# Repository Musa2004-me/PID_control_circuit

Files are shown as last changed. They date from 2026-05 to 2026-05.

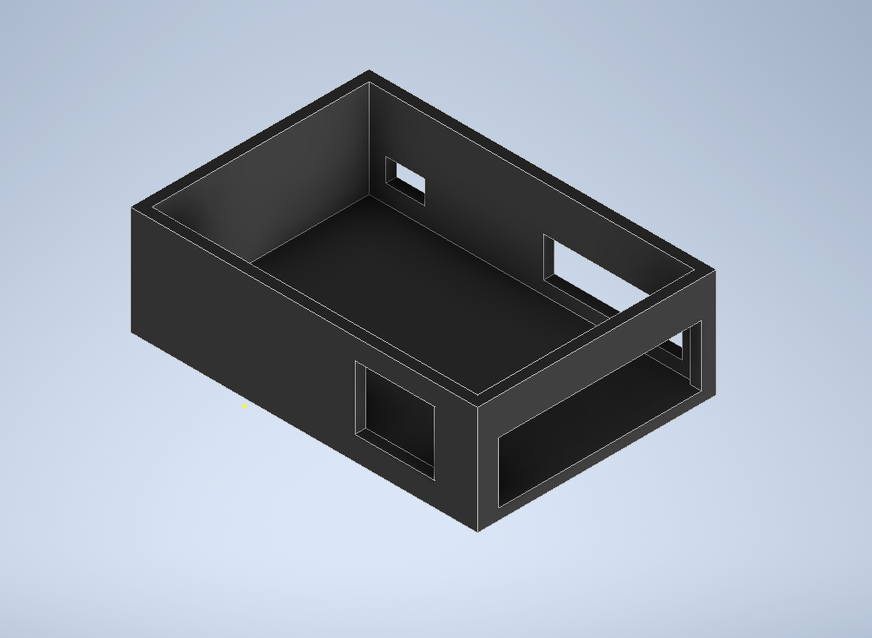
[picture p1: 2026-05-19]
ENCLOSURE.png

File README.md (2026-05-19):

# Analog PID Control Circuit

**Electronics for Instrumentation — MCT232s | Ain Shams University**
Team 27 — Musa Gamal, Fares Mohamed, Youssef Kamel

---

## What is this project?

This project is a fully analog PID controller built using op-amps. It controls the position angle of a DC motor by continuously comparing the desired setpoint (set by a potentiometer) against the actual motor position (read by an encoder), and adjusting the motor drive signal to minimize the error.

The analog circuit is connected to an Arduino UNO which interfaces with MATLAB Simulink for real-time monitoring and a DAC (MCP4725) to close the feedback loop.

---

## How it works

A potentiometer sets the desired angle as a voltage. A subtractor op-amp computes the error between the setpoint and the feedback. That error is then processed by three parallel op-amp stages — Proportional, Integral, and Derivative — whose outputs are summed and sent to the motor driver.

Each of the three gains (Kp, Ki, Kd) is adjustable in real time using potentiometers on the PCB.

---

## The Circuit

The full circuit was designed and simulated in Proteus. It includes input buffering, two low-pass filters to remove noise, a subtractor, the PID block, an adder, and output scaling amplifiers to match the Arduino's 5V ADC range.

---

## PID Gains

| Term | Gain Range | Components |
|---|---|---|
| Proportional (Kp) | 0 → 100 | 100kΩ pot, 1kΩ resistor |
| Integral (Ki) | 55 → 666 | 50kΩ pot, 5kΩ resistor, 0.3µF cap |
| Derivative (Kd) | 0 → 88 | 200kΩ pot, 440µF cap |

---

## Simulation Results

The full closed-loop system was simulated in Simulink with the motor modeled as:

$$G(s) = \frac{1}{s^2 + 10s + 20}$$

With a step input the system settles in around 4 seconds with no overshoot.

Setting the setpoint to 2.51V in the hardware-in-the-loop test, the output tracked it closely at ~2.5V.

---

## PCB

The board was designed using the LM348N quad op-amp IC to keep it as compact as possible. The three potentiometers for Kp, Ki, Kd are accessible on the top of the board.

---

## Tools

- **Proteus** — circuit simulation
- **MATLAB Simulink** — system simulation and hardware-in-the-loop testing
- **Arduino UNO** — analog interface
- **MCP4725** — DAC for feedback signal
- **LM348N / µA741** — op-amps

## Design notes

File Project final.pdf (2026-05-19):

AIN SHAMS UNIVERSITY-FACULTY OF ENGINEERING

## [MCT232s]

Electronics for Instrumentation

PID control circuit

## Project report

## Team 27

Name | ID | Section (MCT)
Musa Gamal El-Shenawy | 2100614 | 1
Fares Mohamed Mostafa | 2100409 | 1
Youssef Kamel Ahmed | 2101081 | 1

Table of Contents

### Introduction:

A PID controller, which stands for Proportional-Integral-Derivative controller, is a widely used tool in industrial control systems for regulating various physical quantities like temperature, flow, pressure, and speed. It utilizes a feedback loop to continuously monitor and adjust a process variable to match a desired setpoint.

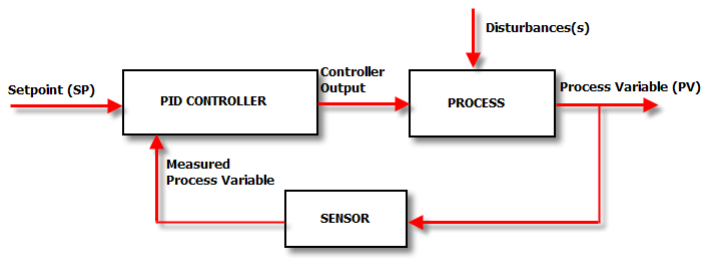
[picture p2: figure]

Operation principle:
1. Measures the Error: The PID controller constantly watches the difference between the setpoint (SP) and the actual measured value of the output (PV), calculating the error.
2. Threefold Response: The controller then calculates a response based on three terms:
- Proportional (P) Term: This term reacts to the current magnitude of the error. A larger error results in a larger response from the controller.

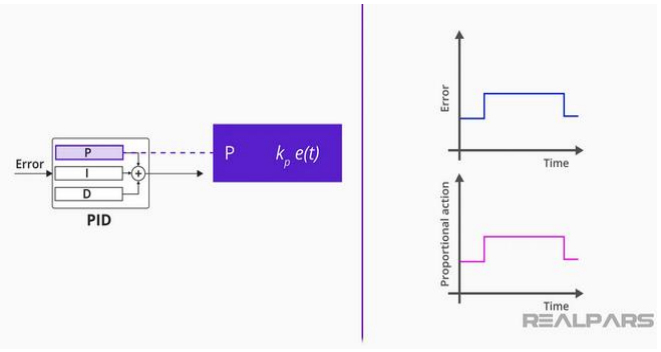
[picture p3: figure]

- Integral (I) Term: This term addresses long-term errors by accumulating the error over time. It helps eliminate any steady-state error, where the process variable remains slightly off the setpoint.
- Derivative (D) Term: This term anticipates future errors based on the rate of change of the error signal. It helps the controller react quickly to changes and reduces overshoot, where the process variable briefly goes beyond the desired setpoint.

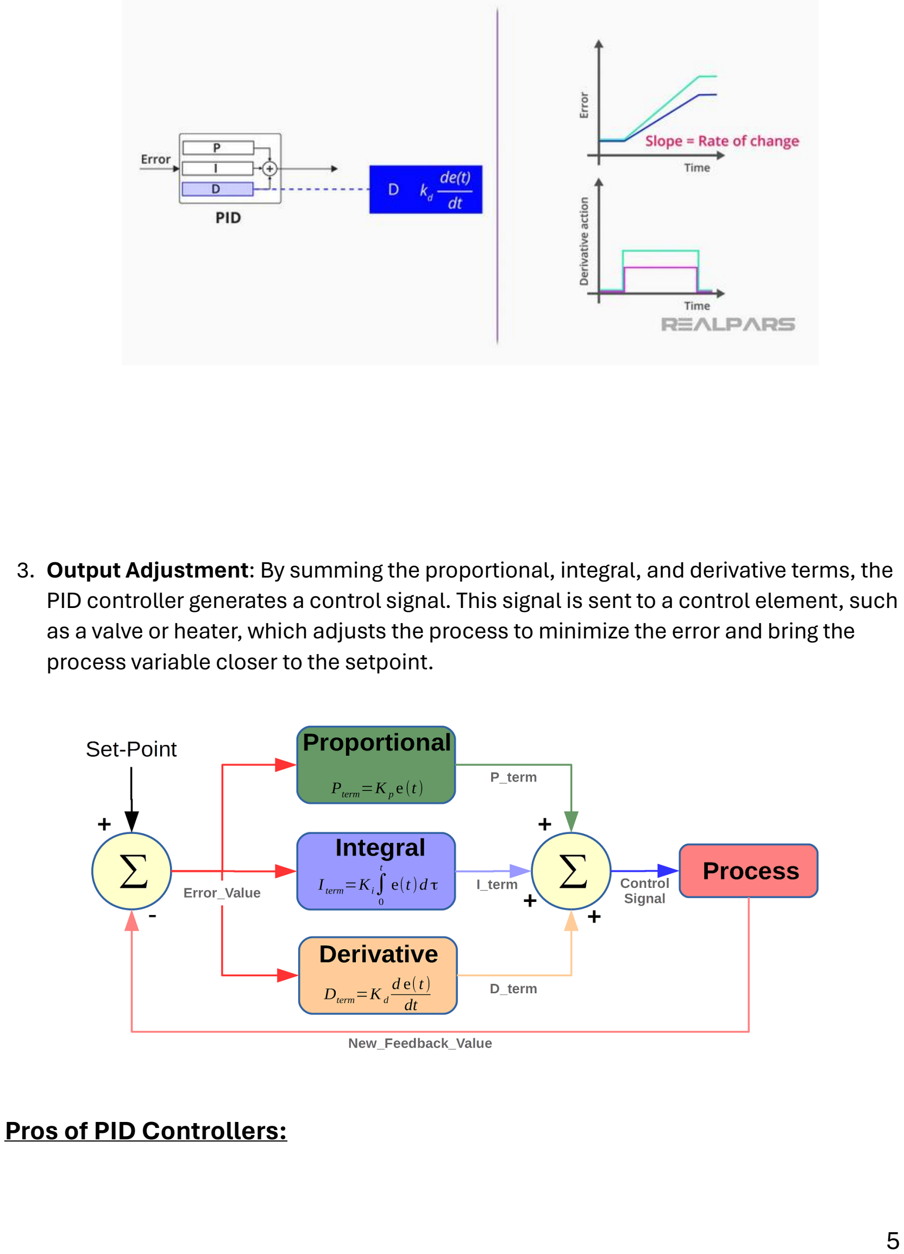
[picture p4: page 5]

3. Output Adjustment: By summing the proportional, integral, and derivative terms, the PID controller generates a control signal. This signal is sent to a control element, such as a valve or heater, which adjusts the process to minimize the error and bring the process variable closer to the setpoint.

Pros of PID Controllers:

Versatility: They can be applied to a vast range of processes thanks to their adjustable parameters. They can handle variables like temperature, pressure, flow, and speed across various industries.
Effectiveness: The combination of proportional, integral, and derivative actions in a PID controller allows for precise and stable control. The proportional term reacts immediately to errors, the integral term eliminates long-term drifts, and the derivative term anticipates future changes to prevent overshoot.
Simplicity: The core concept behind PID control is relatively easy to understand. While tuning the specific parameters (P, I, D) requires some know-how, the basic principles are accessible.
Cost-effective: PID controllers can be implemented using various technologies, from analog circuits to digital microprocessors. This makes them adaptable and affordable for a wide range of applications.

Cons of PID Controllers:

Tuning Time: While the concept is simple, achieving optimal performance from a PID controller requires careful tuning of the proportional, integral, and derivative gains. This tuning process can be time-consuming, especially for complex systems.
Limitations with Non-Linear Systems: PID controllers work best with linear systems where the output has a proportional relationship to the input. In highly non-linear systems, achieving optimal control with a PID controller can be challenging.
Not Ideal for Processes with Large Time Delays: If there's a significant delay between the control action and the observed effect in the process, a PID controller might struggle to maintain stability.

### Project objective:

The project objective is to design a PID circuit using op amps to control a motor position-angle when an input set-point is used with minimal error and fastest speed possible.

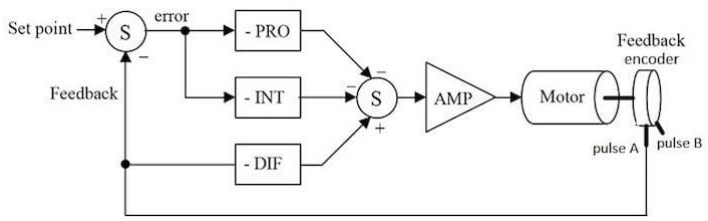
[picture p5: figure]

Desired response:
1. Risetime: the time the response rise to the set point.
2. Overshoot: is the amount the value rise above the set point

3. Settling time: the time the response settles to steady state.
4. steady-state error: the value that the response stays on away from the setpoint. -And they all should be minimised

These parameters can be controlled using the value of Kp,Ki,Kd

## Circuit:

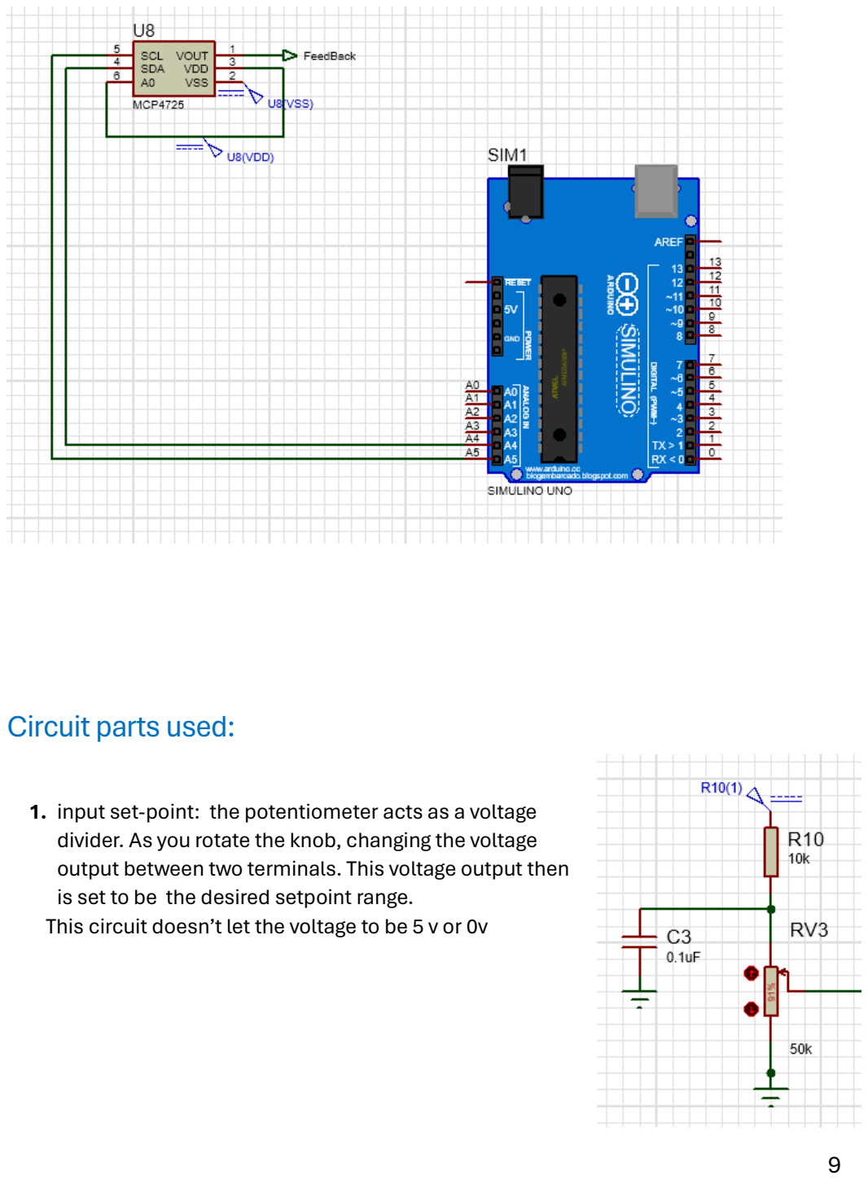
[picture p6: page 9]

### Circuit parts used:

### 1. input set-point: the potentiometer acts as a voltage

divider. As you rotate the knob, changing the voltage output between two terminals. This voltage output then is set to be the desired setpoint range.
This circuit doesn’t let the voltage to be 5 v or 0v

### 2. buffer: A buffer is used to isolate the load from the

source.

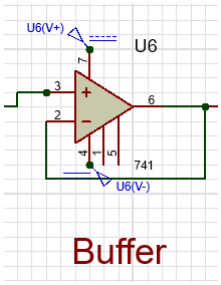
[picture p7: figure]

3. inverting amplifier: it is used to make the the signal positive with unity gain.

### 4. low-pass filter: a filter is added before the circuit

to remove any high frequency noise from the system.
And to rise the voltage smoothly .

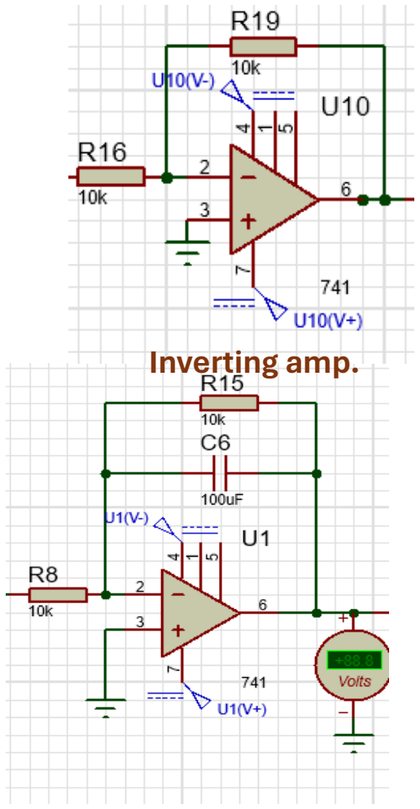
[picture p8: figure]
Inverting amp.

feedback

### 5. Subtractor: The subtractor is used as a

comparator it compares the feedback with the input signal and check if there is an error.

### 6. Low-pass filter:

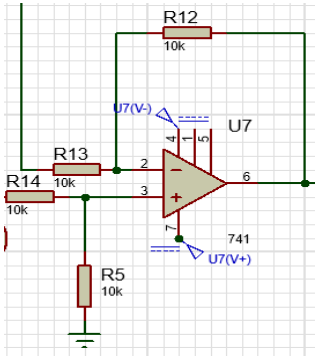
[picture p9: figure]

a filter is added before the circuit to remove any high frequency noise from the system.

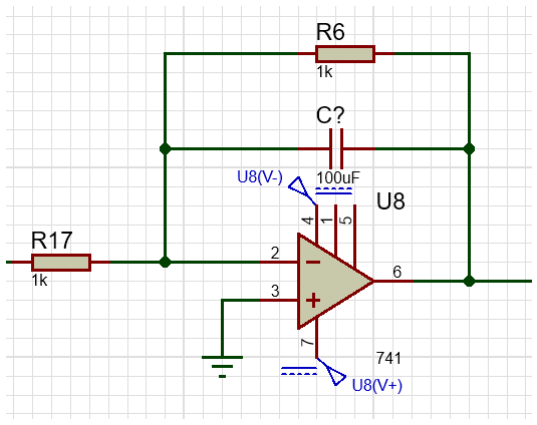
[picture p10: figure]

### 7. Proportional amplifier: An inverting amplifier configuration can be used to directly

scale the error signal (difference between setpoint and process variable).

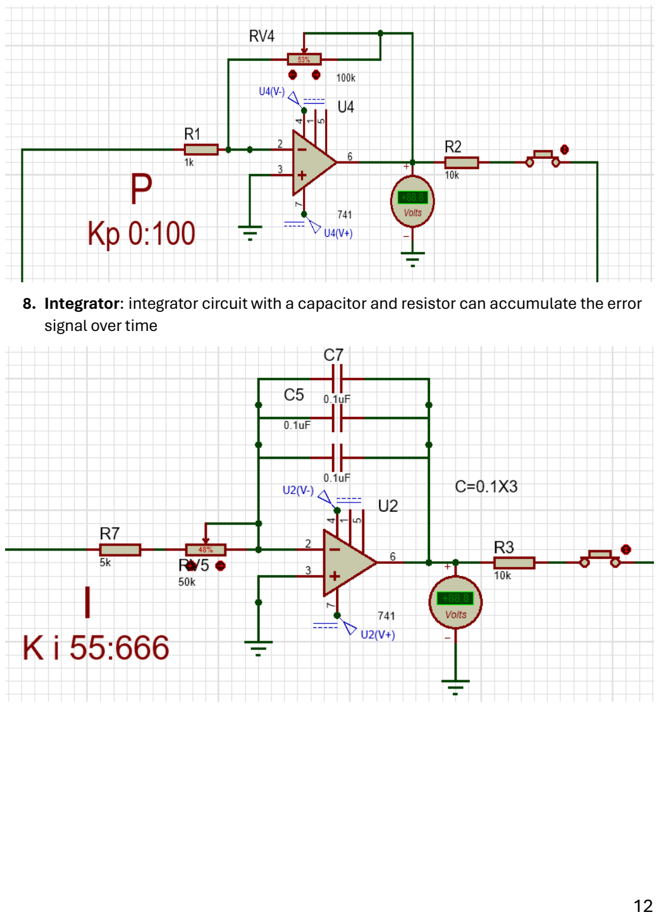
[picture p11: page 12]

### 8. Integrator: integrator circuit with a capacitor and resistor can accumulate the error

signal over time

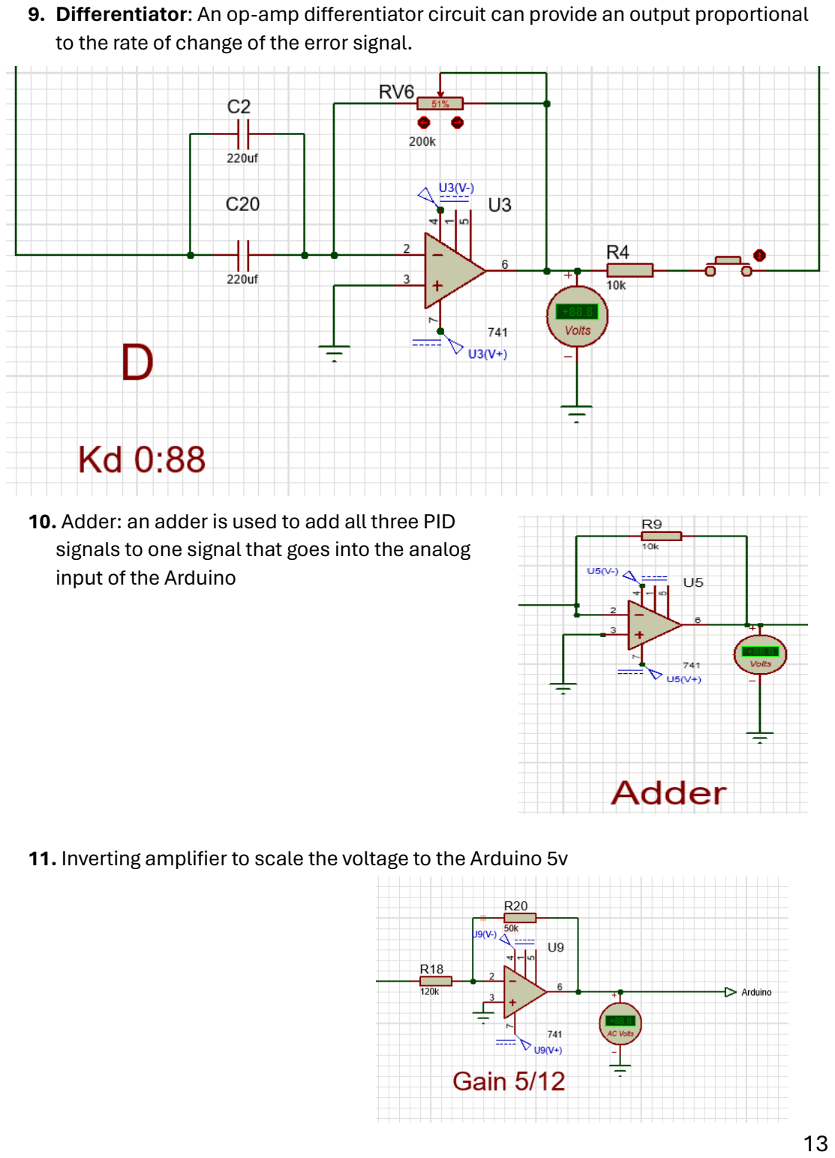
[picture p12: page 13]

### 9. Differentiator: An op-amp differentiator circuit can provide an output proportional

to the rate of change of the error signal.

### 10. Adder: an adder is used to add all three PID

signals to one signal that goes into the analog input of the Arduino

### 11. Inverting amplifier to scale the voltage to the Arduino 5v

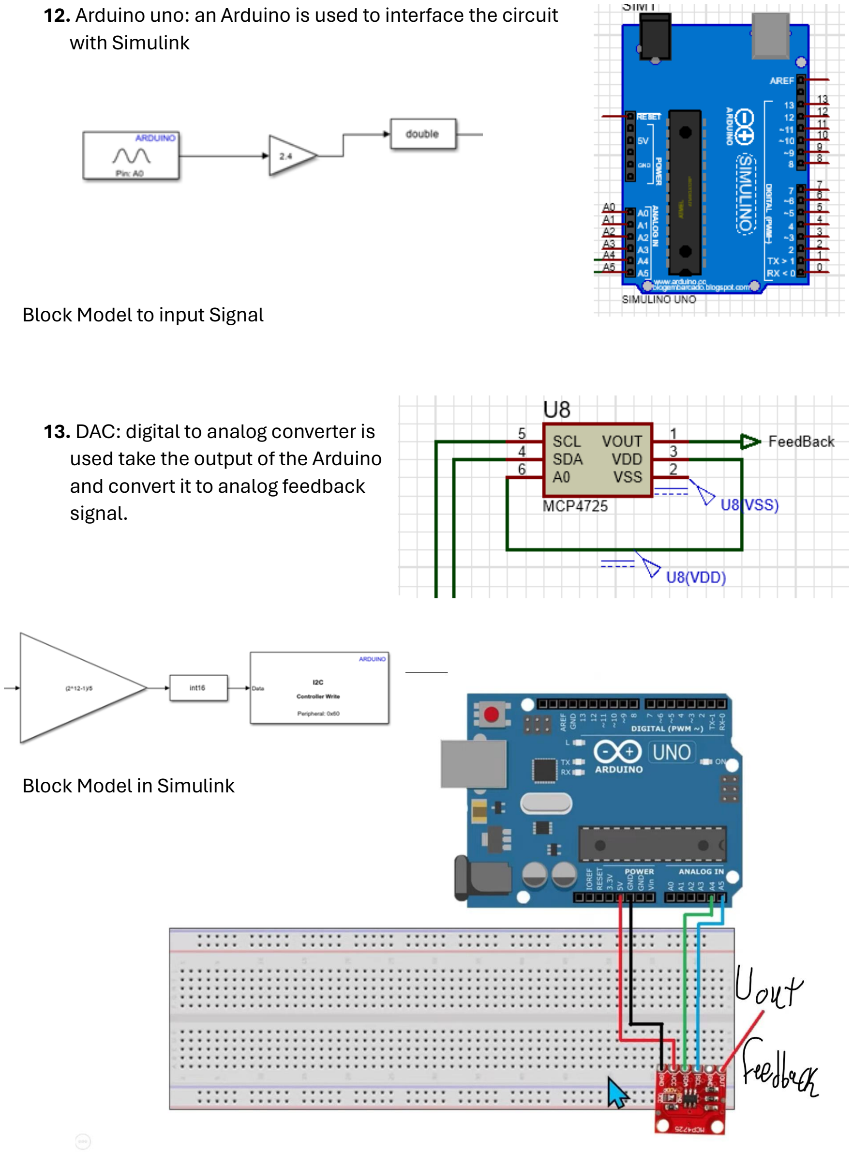
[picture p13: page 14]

### 12. Arduino uno: an Arduino is used to interface the circuit

with Simulink

Block Model to input Signal

### 13. DAC: digital to analog converter is

used take the output of the Arduino and convert it to analog feedback signal.

Block Model in Simulink

### Calculations:

1)Set Point <5v
From this ratio I can reach 0.84v and less V(max)=5x

50
60

=4.167v
V(min)=0v

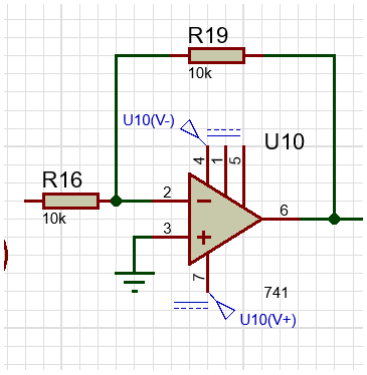
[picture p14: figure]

2)inverting Amp with Gain=-1Vset Av=-1

### 3) buffer

V1=V2
A(v)=1

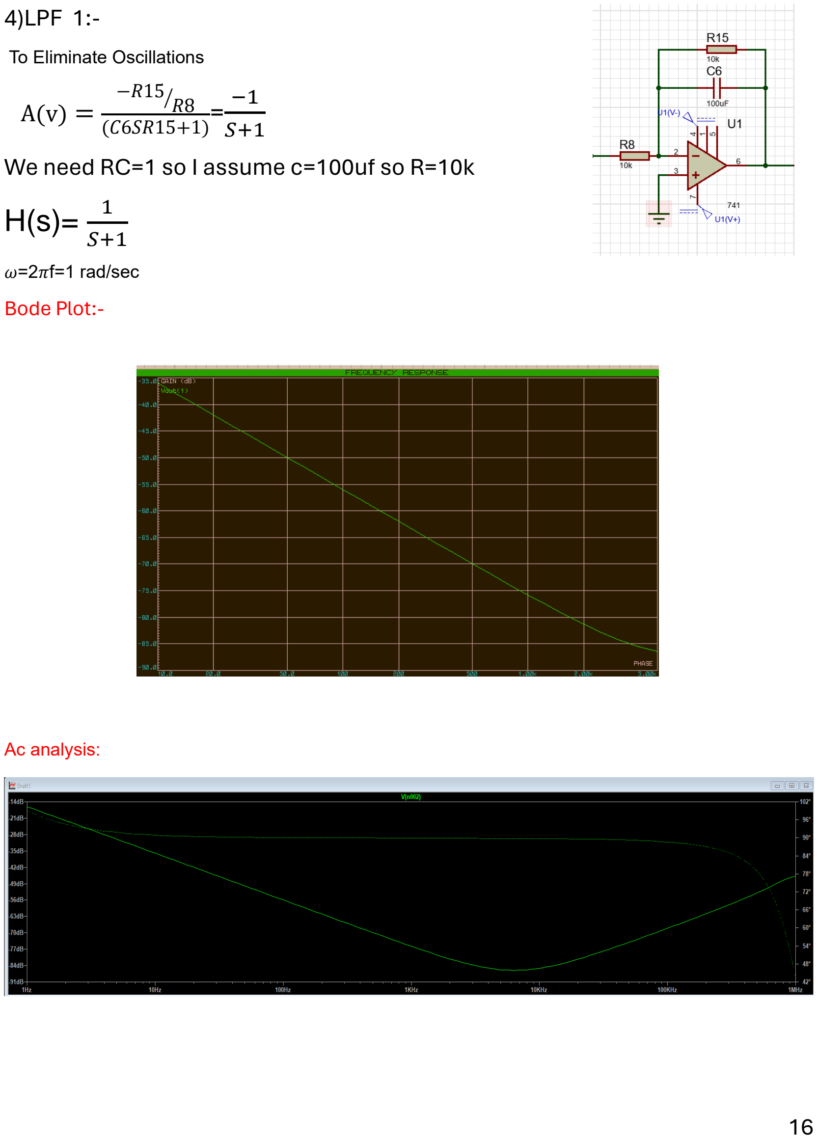
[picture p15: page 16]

4)LPF 1:-

To Eliminate Oscillations

A(v) =

−R15
R8

⁄
(C6SR15+1)

=

−1
S+1
We need RC=1 so I assume c=100uf so R=10k H(s)= 1
S+1

ω=2πf=1 rad/sec
Bode Plot:-

Ac analysis:

### 5)subtractor

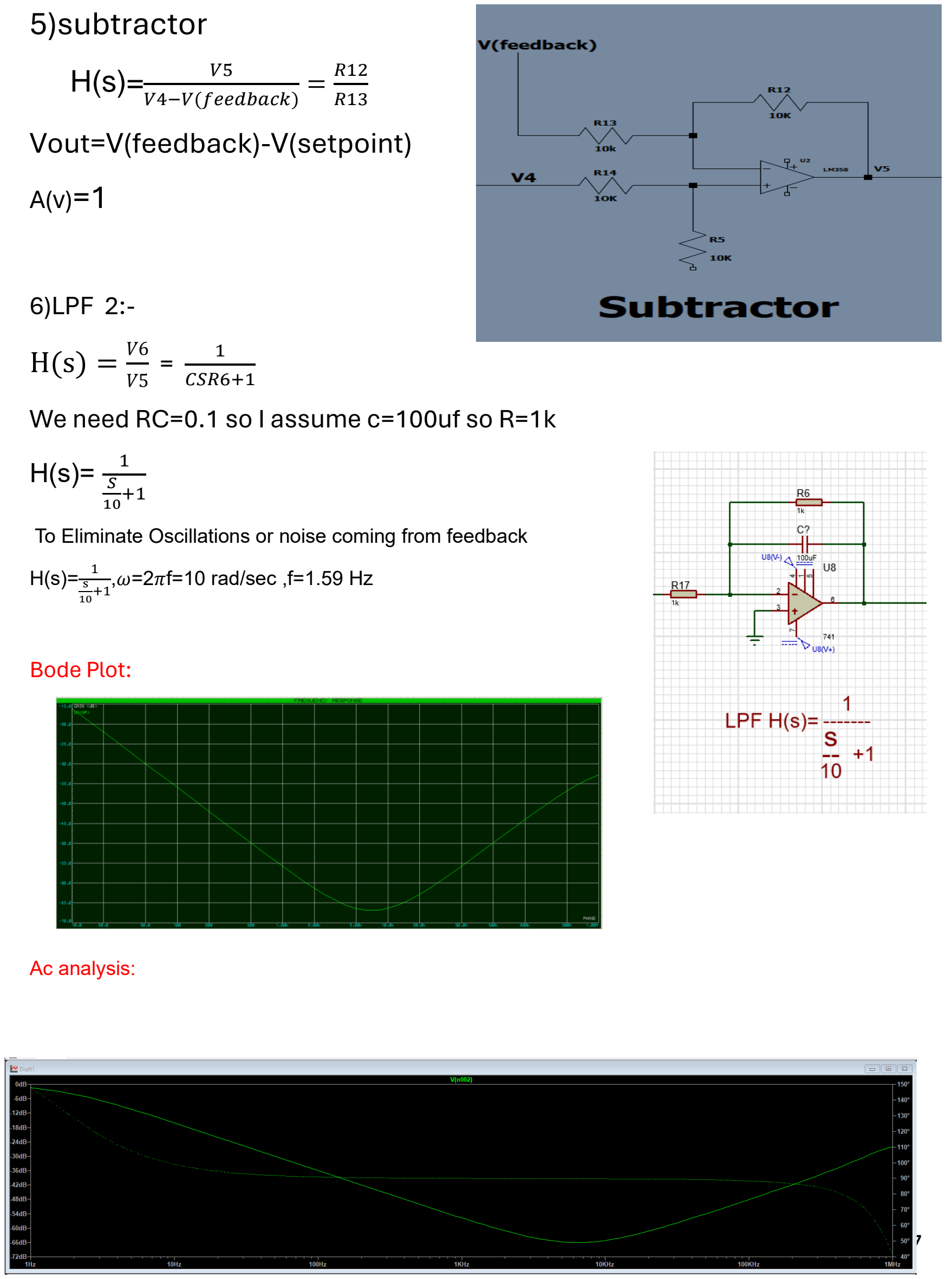
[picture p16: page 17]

H(s)= V5
V4−V(feedback)

=

R12
R13
Vout=V(feedback)-V(setpoint) A(v)=1

6)LPF 2:-

H(s) =

V6
V5

=

| 1 CSR6+1

We need RC=0.1 so I assume c=100uf so R=1k

H(s)= 1
S
10+1

To Eliminate Oscillations or noise coming from feedback

H(s)= 1
s
10

+1

,ω=2πf=10 rad/sec ,f=1.59 Hz

Bode Plot:

Ac analysis:

### 7)PID

P : A(v)=

−RV4
R1
Kp=50 when Pot at center →⁵⁰
1

=50

I : A(v)=

−1
CS(R7+RV5)
Since Ki=100 take C=0.3μf and R7+Rv1=(5k+50kpot)=55k So that the min R=5k and max=105k
We add R=5k to the integrator to to be
far away of infinite gain.

D : A(v)= −CSRV6
Since Kd=50 take C=440μf and Rv6=50k (midpoint)

We use 3 Pot in PID To be able to change the values of Kp,I,d.

-As Kp= Rpot
Rconst

we use a Pot 100kohm and R1 kohm to vary the Kp in range of

Kp →0:100 .

-As Ki=

1
(Rpot+Rconst)C

we use a pot and const R to be far away of infinite

gain.

we use a Pot 50kohm and R 5kkohm to vary the Ki in range of Ki →55:666 .

-As Kd=Rpot C we use a pot 50k and 2uf capacitor to vary the Ki in range of

Ki →0:88 .

### 8)Adder

H(s) =

Vout
V8

= −R9(

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
### A(v)=-(Vp+Vi+Vd)

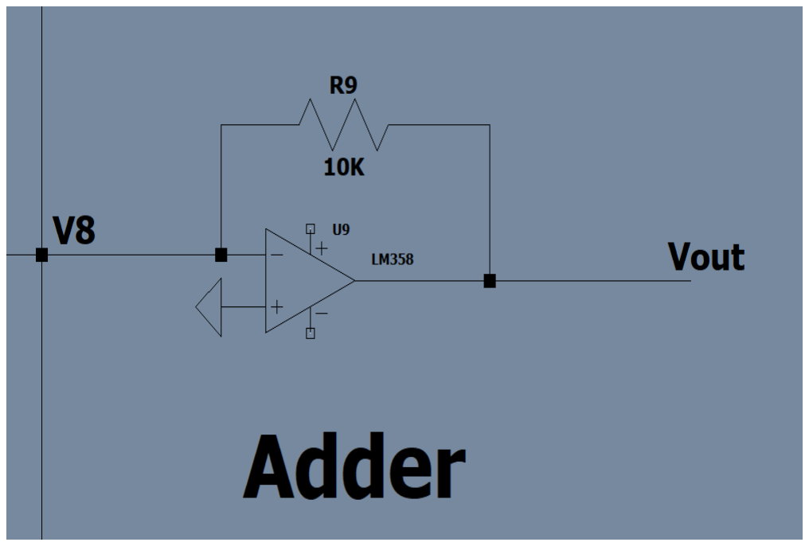
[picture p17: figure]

*because of we need mapping to send and receive signal to -from arduino we made to op-amp circuit to mappingthe circuit.

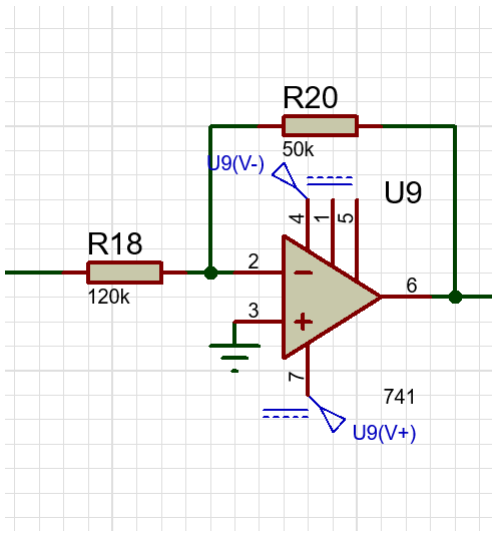
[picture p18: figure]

9) inverting amplifier

A(v)= gain =

−5
12

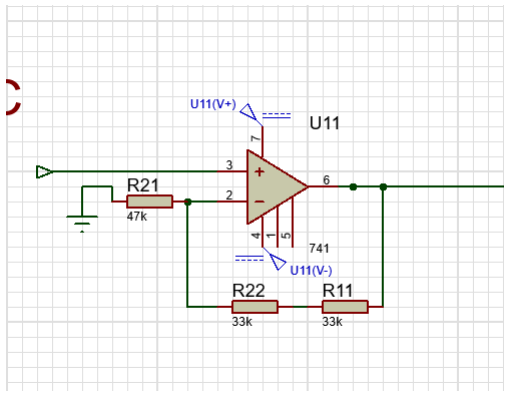
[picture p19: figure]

10) Non-inverting amplifier

A(v)= gain = 1 +

66
47

= 12/5

### (P-I-D) Test:-

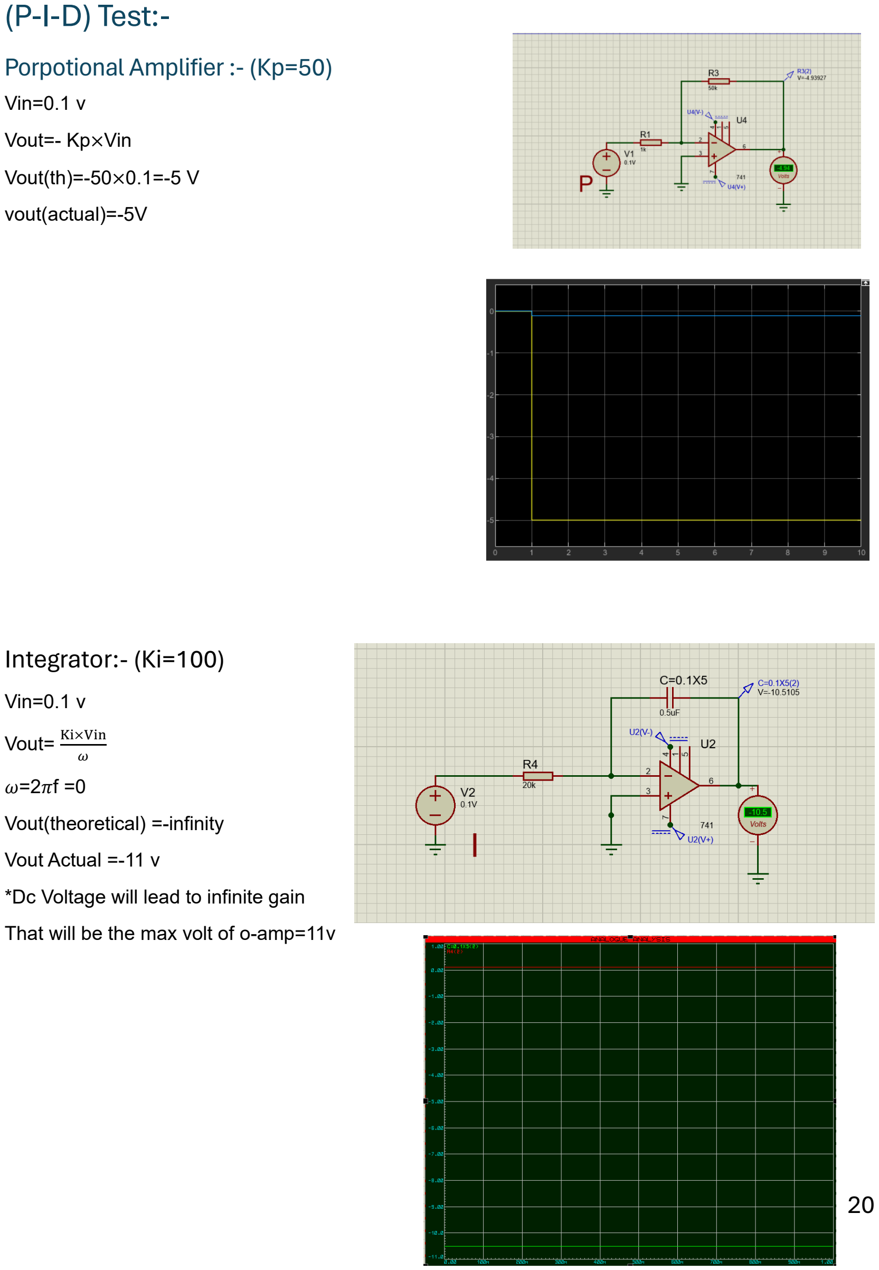
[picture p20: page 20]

Porpotional Amplifier :- (Kp=50)

Vin=0.1 v

Vout=- Kp×Vin

Vout(th)=-50×0.1=-5 V

vout(actual)=-5V

Integrator:- (Ki=100)

Vin=0.1 v

Vout= Ki×Vin
ω
ω=2πf =0

Vout(theoretical) =-infinity

Vout Actual =-11 v

*Dc Voltage will lead to infinite gain

That will be the max volt of o-amp=11v

Differentiator:-(Kd=10)

Vout=- Kd × Vin × ω

ω=2πf=0

Vin=0.1v

Vout(theoretical)= 0

Vout Actual =0.01mv

*Dc voltage will lead to 0 gain.

### PID Test:-

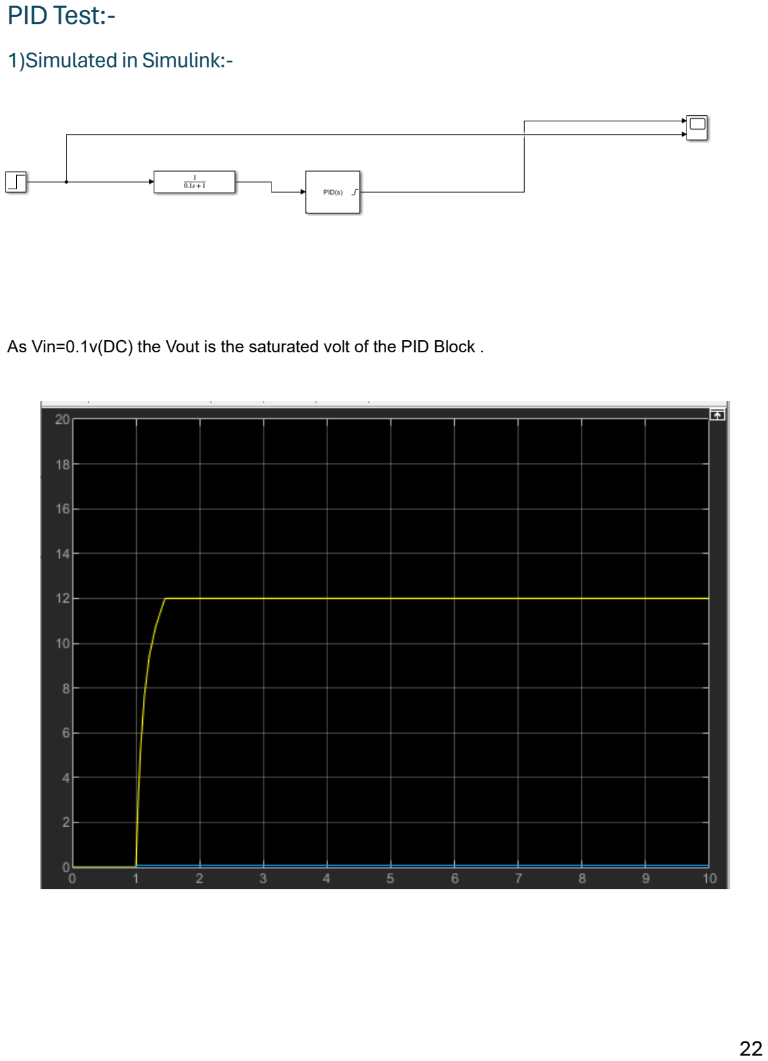
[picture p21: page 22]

1)Simulated in Simulink:-

As Vin=0.1v(DC) the Vout is the saturated volt of the PID Block .

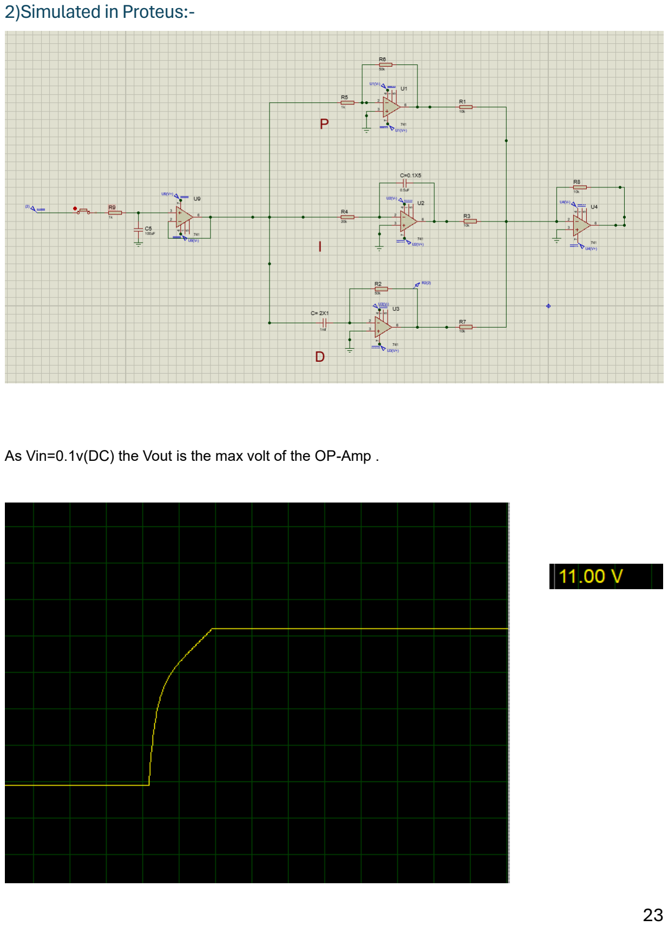
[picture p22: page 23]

2)Simulated in Proteus:-

As Vin=0.1v(DC) the Vout is the max volt of the OP-Amp .

### PCB Layout:-

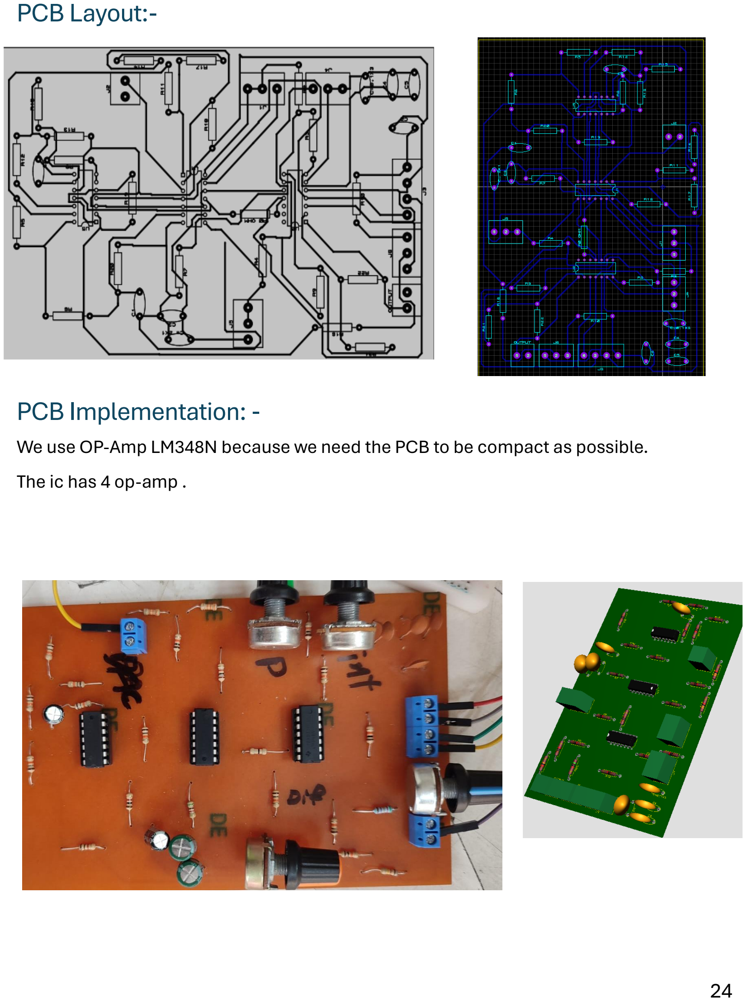
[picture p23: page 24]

### PCB Implementation: -

We use OP-Amp LM348N because we need the PCB to be compact as possible. The ic has 4 op-amp .

### All System Simulated in Simulink:-

With Vin=0.1

Time to reach error is 4 sec

### Implementation the project with Simulink :-

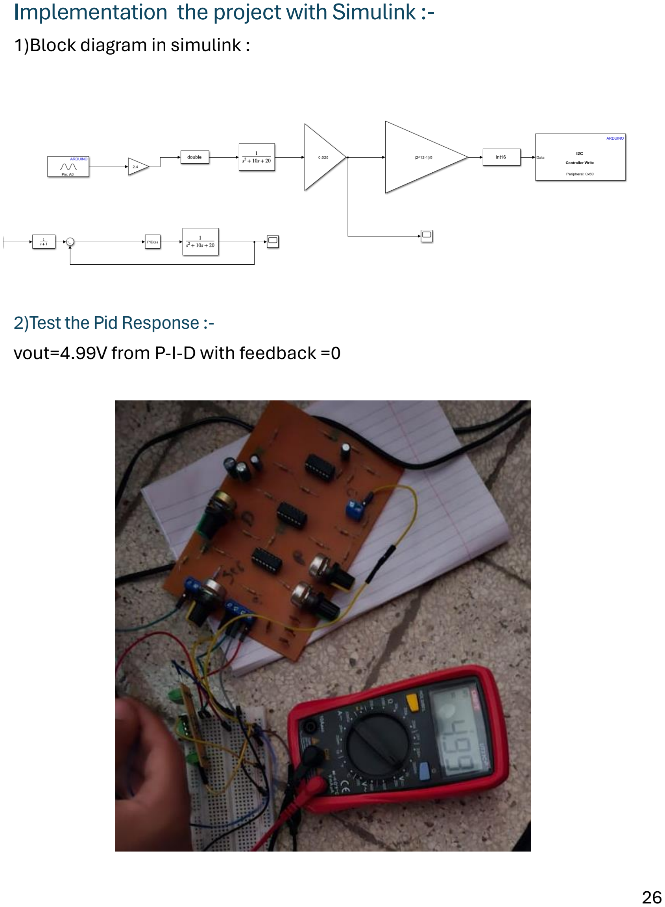
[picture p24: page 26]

1)Block diagram in simulink :

2)Test the Pid Response :-
vout=4.99V from P-I-D with feedback =0

TF Response:-
Set point =2.51v the Transfer Function response varies about 2.5v

### System Encloser:

Not implemented

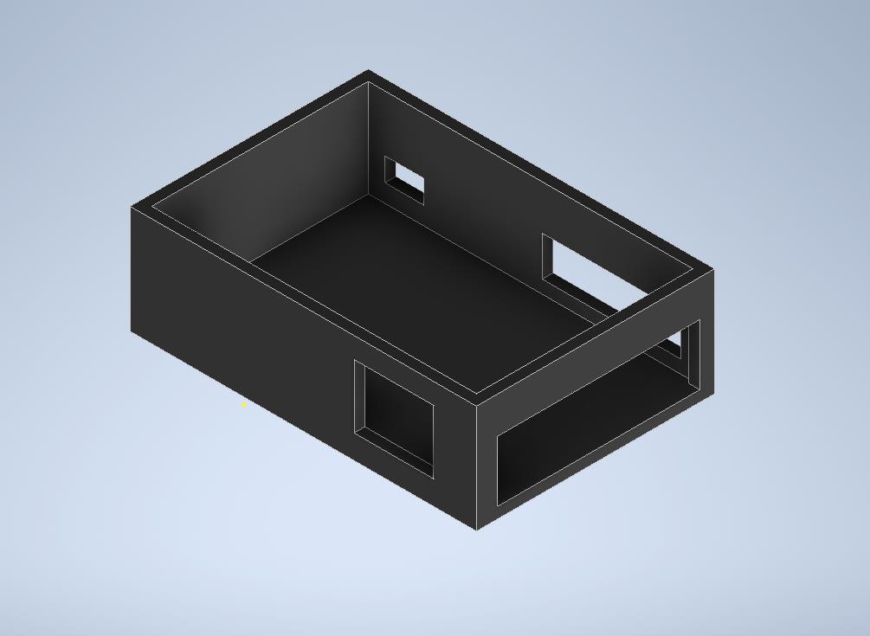
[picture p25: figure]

### Conclusion: -

The simulated curve of implemented circuit has many Errors it should be

1- From the Simulink Block model
2- the communication between the DAC and Arduino and PID has something Wrong.

*We make sure that all connection are good and all op-amp work good So we sure that the Error From Simulink.

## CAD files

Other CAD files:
ENCLOSURE/Part1.ipt

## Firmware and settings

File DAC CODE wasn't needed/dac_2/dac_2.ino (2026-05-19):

#include <Wire.h>
#include <Adafruit_MCP4725.h>

Adafruit_MCP4725 dac;

int analogs=A0;
int PWM_Value=0;


void setup()
{
  dac.begin(0x63);

  pinMode(analogs,INPUT);
  
}

void loop()
{  
  PWM_Value= analogRead(analogs);
  PWM_Value=map(PWM_Value,0,1023,0,4095);
  dac.setVoltage(PWM_Value, false);
 
}
